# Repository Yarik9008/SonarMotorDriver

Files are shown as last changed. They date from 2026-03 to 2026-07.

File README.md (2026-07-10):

# SonarMotorDriver

Проект драйвера шагового двигателя с замкнутым контуром управления (PID) по абсолютному энкодеру LENZ IRS (BiSS C). В репозитории — прошивка для **STM32F103C8**, 3D-сборка платы, даташиты и иллюстрации.

> **Примечание:** Управление TMC2209 по UART (ток, микрошаг, вращение) проверено на аппаратуре целевой платы — мотор вращается, энкодер отвечает, драйвер подтверждает конфигурацию (`mcfg`). Пин **DIAG** (StallGuard/Open Load) разведён, но программно не опрашивается.

## Иллюстрации

| CAD: сборка с радиатором | CAD: сборка с прозрачным кожухом |
| --- | --- |
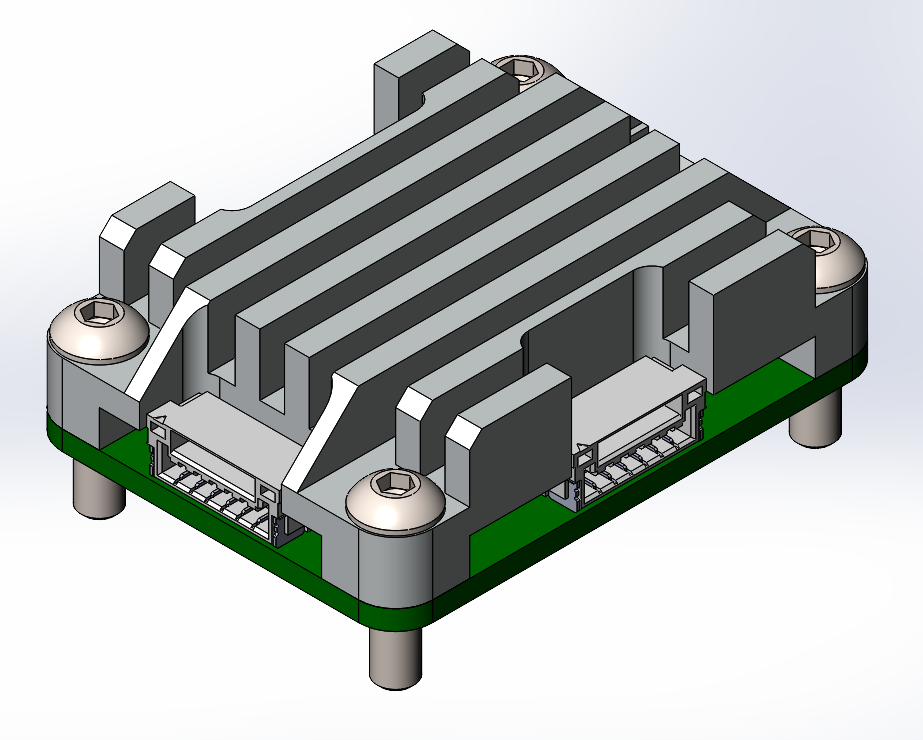
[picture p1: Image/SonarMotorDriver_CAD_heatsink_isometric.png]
CAD сборка с радиатором
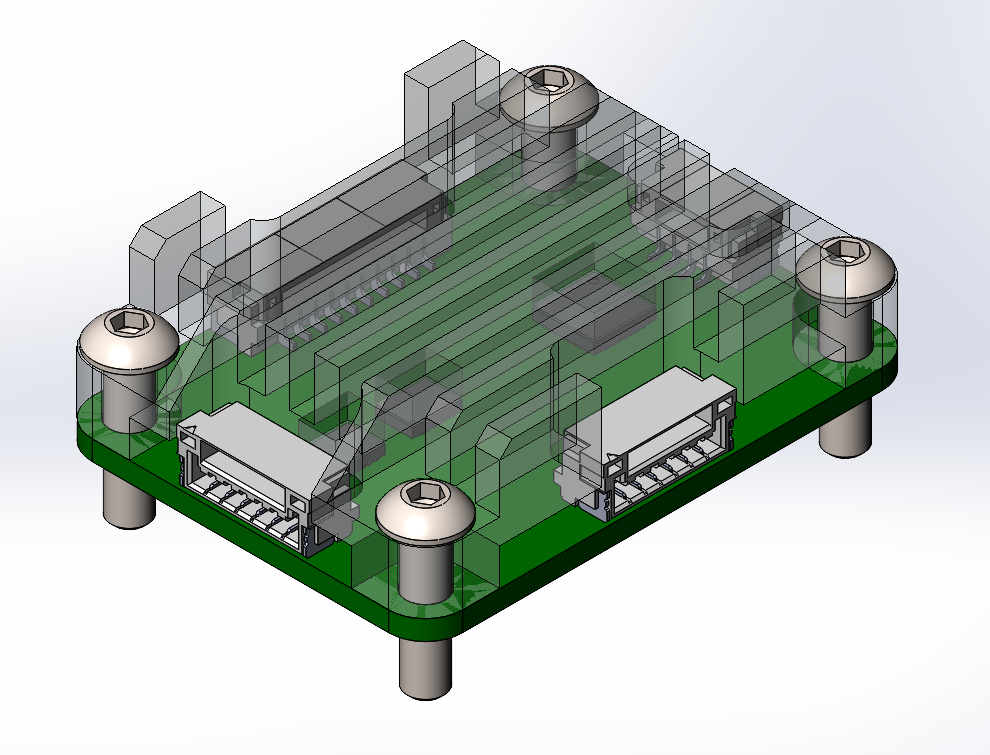
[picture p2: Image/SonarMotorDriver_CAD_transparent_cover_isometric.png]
CAD сборка с прозрачным кожухом
|  |  |

| Плата: верхний слой (релиз 0.1) | Плата: нижний слой (релиз 0.1) |
| --- | --- |
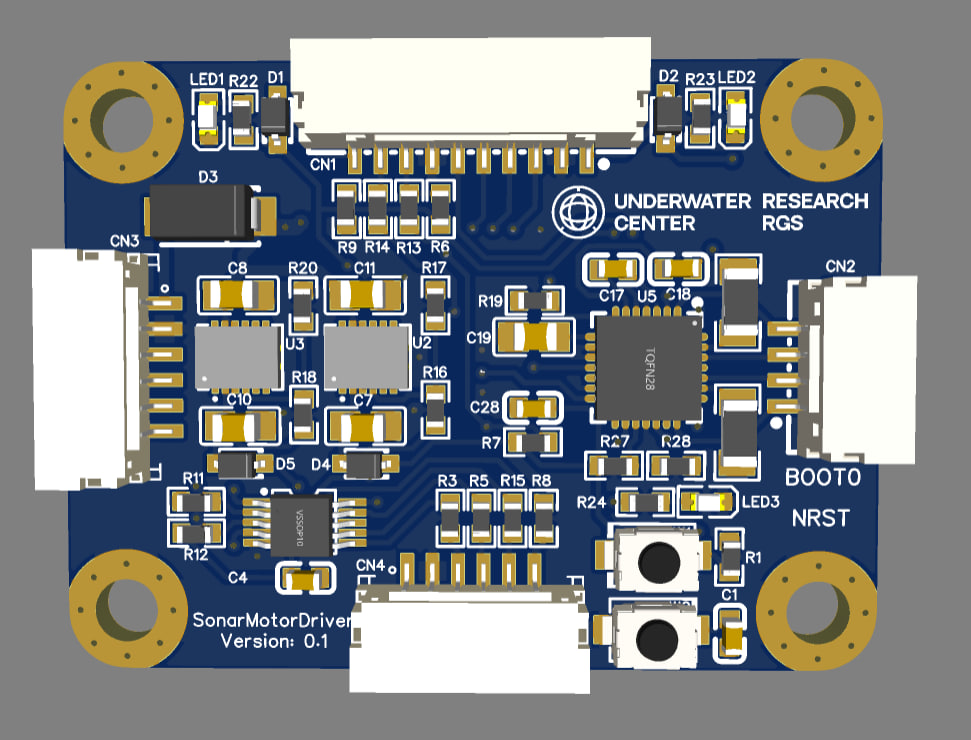
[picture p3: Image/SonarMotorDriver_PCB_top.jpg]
Верхний слой платы SonarMotorDriver
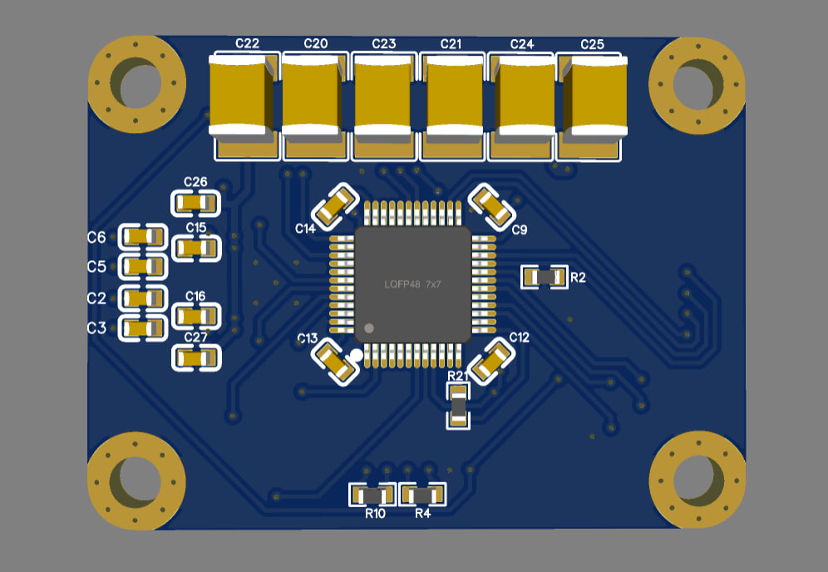
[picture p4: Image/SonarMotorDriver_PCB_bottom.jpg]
Нижний слой платы SonarMotorDriver
|  |  |

## Структура репозитория

| Каталог | Описание |
|---|---|
| [**Software/FW_SonarMotorDriver/**](Software/FW_SonarMotorDriver/) | Основная прошивка STM32F103C8: PID, энкодер BiSS C, TMC2209, **UART** (команды и телеметрия), IWDG |
| [**Software/FW_SonarMotorDriver_Sim/**](Software/FW_SonarMotorDriver_Sim/) | Имитатор основной прошивки: тот же UART-протокол (команды и телеметрия), но без реального энкодера и TMC2209 — для отладки ПО верхнего уровня без подключённого мотора |
| [**Software/Test_TMC2209/**](Software/Test_TMC2209/) | Отладочная прошивка **STM32F103C8** + TMC2209: **UART CLI** через внешний USB-UART переходник, проверка драйвера отдельно от основной платы |
| [**Hardware/CAD/**](Hardware/CAD/) | 3D-модели (SolidWorks/STEP): сборка с радиатором и кожухом, радиатор, STEP компонентов BOM |
| [**Docs/Datasheet/**](Docs/Datasheet/) | PDF-даташиты ключевых компонентов (STM32, TMC2209, THVD1452, питание, разъёмы и т.д.) |
| [**Image/**](Image/) | Рендеры платы и CAD для документации |

## Возможности (основная прошивка)

- **PID** — замкнутый контур по энкодеру, привязка к микрошагу, переход в open-loop при потере связи с энкодером
- **LENZ IRS** — абсолютная позиция 17–18 бит по BiSS C (SPI + DMA + THVD1452)
- **TMC2209** — STEP/DIR/ENABLE, UART для тока и микрошага
- **UART (USART1)** — текстовые команды и телеметрия (период настраивается, режимы `debug=0` / `debug=1`)
- **IWDG** — сторожевой таймер

Подробности, распиновка, протокол команд и BiSS C — в [Software/FW_SonarMotorDriver/README.md](Software/FW_SonarMotorDriver/README.md).

## Быстрый старт (сборка основной прошивки)

```bash
cd Software/FW_SonarMotorDriver
pio run                    # сборка
pio run --target upload    # прошивка (см. platformio.ini: ST-Link / WCH-Link + OpenOCD)
```

Имитатор UART-протокола (без мотора и энкодера): [Software/FW_SonarMotorDriver_Sim/README.md](Software/FW_SonarMotorDriver_Sim/README.md).
Тестовая прошивка драйвера TMC2209: [Software/Test_TMC2209/README.md](Software/Test_TMC2209/README.md).

## Требования

- **PlatformIO** — сборка прошивок в `Software/`
- **Программатор** — ST-Link, CMSIS-DAP или иной, совместимый с настройками `upload` в `platformio.ini`

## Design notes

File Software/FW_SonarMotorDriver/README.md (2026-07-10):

# FW_SonarMotorDriver — Closed-Loop Stepper

Прошивка для STM32F103C8 (Blue Pill): позиционное управление шаговым двигателем
через **TMC2209** с обратной связью от абсолютного энкодера **LENZ IRS** (BiSS C).
При потере энкодера — автоматический переход в **open-loop**. Настройка и мониторинг — через **UART** (PA9/PA10).

> **Примечание:** Управление TMC2209 по UART (ток, микрошаг, вращение STEP/DIR) проверено на аппаратуре — мотор вращается, энкодер отвечает (`ec:0`), `mcfg` подтверждает конфигурацию драйвера. Пин **DIAG** (StallGuard/Open Load) разведён, но программно не опрашивается.
>
> **См. также:** [FW_SonarMotorDriver_Sim](../FW_SonarMotorDriver_Sim/README.md) — имитатор этого же UART-протокола без реального энкодера и TMC2209, для отладки ПО верхнего уровня.

## Содержание

- [Архитектура](#архитектура)
- [Аппаратная часть](#аппаратная-часть)
- [Структура проекта](#структура-проекта)
- [Сборка и прошивка](#сборка-и-прошивка)
- [Использование](#использование)
- [Конфигурация](#конфигурация)
- [API модулей](#api-модулей)
- [Протокол BiSS C](#протокол-biss-c)
- [Устранение неисправностей](#устранение-неисправностей)

---

## Архитектура

```
                    Замкнутый контур управления (1 кГц)

 Уставка       ошибка   ┌─────────┐   шаги    ┌──────────────────────┐
 (t=X) ──────►(Σ)──────►│   PID   ├──────────►│ MotorDriver          ├──────► Мотор
               ▲ −      │ Kp+Ki+Kd│           │ (STEP_DIR или UART)  │    │
               │        └─────────┘           └──────────────────────┘    │
               │                                                          │
               │        ┌──────────────────┐                              │
               └────────┤  Encoder + BiSS  │◄─────────────────────────────┘
            pos_deg     │  SPI+DMA+THVD1452│   обратная связь
                        └──────────────────┘

 CL: PID(target − pos) → шаги (основной)
 OL: clamp(target − ol_pos) → шаги (при потере энкодера ≥ 500 мс)

 ┌──────┐   UART    ┌──────────┐
 │  ПК  │◄─────────►│   Cmd    ├──► en / dis / t= / t=± / kp= / ki= / kd= / op= / scan= / stop
 │      │  USART1   │  Parser  │
 └──────┘ PA9/PA10  └──────────┘
 ПК ◄── Телеметрия (UART TX): debug=0 → cp,ec; debug=1 → cp,tp,pe,u,m,ec,kp,ki,kd
```

### Режимы управления

| Режим | Условие | Поведение |
| --- | --- | --- |
| **cl** (closed-loop) | Энкодер отвечает | PID по ошибке `target − position`, вывод ограничен deadband |
| **ol** (open-loop) | Энкодер не отвечает ≥500 мс | Прямое позиционирование: `clamp(target − ol_pos)` без PID |

Переключение автоматическое:

- **cl → ol:** после `ENCODER_FAIL_MS` (500 мс) без ответа энкодера.
- **ol → cl:** при первом успешном ответе, интеграл PID сбрасывается.

### Стартовая диагностика энкодера

До включения мотора прошивка выполняет серию из `ENCODER_DIAG_SAMPLES` (16) чтений BiSS C
с интервалом `ENCODER_DIAG_INTERVAL_MS` (2 мс) и разрешает автоматический выход в «дом» только если:

- валидных ответов (OK/WARNING) не меньше `ENCODER_DIAG_MIN_OK` (12 из 16);
- разброс позиции при неподвижном вале не превышает `ENCODER_DIAG_MAX_SPREAD_DEG` (0.5°).

Результат отправляется хосту одной строкой:

```
enc:ok n=16/16 spread=0.004 pos=37.52     ← диагностика пройдена, далее хоуминг
err:enc n=3/16 spread=0.000 last=2        ← провал: мотор остаётся выключенным
```

При провале позиция продолжает отслеживаться, но движение возможно только по явной
команде оператора (`en`, `t=…`). Ту же проверку можно запустить в любой момент командой `diag`
(на остановленном моторе): ответ `ok:diag`, затем через ~16 мс строка `enc:ok` / `err:enc`.

### Фильтр выбросов показаний энкодера

CRC6 кадра BiSS слабая (искажённый кадр проходит проверку с вероятностью ~1/64), поэтому
поверх CRC работает фильтр правдоподобия: показание отбрасывается, если сдвиг от последней
принятой позиции превышает физически возможный — `ENCODER_OUTLIER_MAX_DELTA_DEG` (3°) за тик
1 мс (потолок скорости 1200°/с = 1.2°/мс, порог с запасом 2.5×). Бюджет сдвига масштабируется
на длительность пропуска данных (до 60° — дальше дельта неоднозначна из-за перехода через ноль).

- Отброшенное показание не попадает в контур управления (тик считается «без данных»),
  в телеметрии на этот момент `ec:6`, накопительный счётчик — поле `of` (debug=1).
- Реальный скачок позиции (проскальзывание муфты, восстановление энкодера после долгой
  потери связи на ходу) отличается от выброса устойчивостью: `ENCODER_OUTLIER_STREAK` (3)
  согласных чтений подряд — и новая позиция принимается (перепривязка за ~3 мс).

### Контур (1 кГц)

1. **TIM2** — флаг UIF каждые 1 мс.
2. **BiSS C** — чтение позиции через SPI1 + DMA + THVD1452 (неблокирующее).
3. **Encoder_Accumulate** — многооборотная позиция с обработкой перехлёста.
4. **Mode_Update** — счётчик сбоев: ≥500 мс без ответа → ol; при ответе → cl.
5. **MotorControl_Tick** — CL: PID → шаги; OL: прямое позиционирование.
6. **Stall_Tick** — защита от блокировки вала (см. ниже).
7. **Scan_Tick** — сканирование сектора (zigzag start↔end или бесконечное в одном направлении, до команды stop); пин синхронизатора PB9 (SYNC_OUT).
8. **Telemetry_Tick** — периодический вывод (250 Гц по умолчанию): debug=0 → cp,ec; debug=1 → полная.
9. **Heartbeat_Tick** — мигание LED ~1 Гц.

### Профиль движения: скорость и ускорение (v= / a=)

Пределы движения настраиваются на лету, без перепрошивки:

- **`v=<°/с>`** — рабочий предел скорости (1..1200). Действует на все виды движения:
  позиционирование, сканирование, непрерывное вращение. По умолчанию 1200 °/с.
- **`a=<°/с²>`** — предел ускорения (0..100000). По умолчанию **0 = без рампы**
  (скорость меняется мгновенно — поведение как раньше). При `a > 0`:
  - скорость нарастает/спадает не быстрее `a` (трапецеидальная рампа);
  - при подъезде к цели действует тормозной конверт `v ≤ sqrt(2·a·|ошибка|)` —
    мотор успевает остановиться без перелёта.

Текущие значения видны в полной телеметрии (`debug=1`, поля `v` и `a`).
Ограничение применяется поверх PID: выход регулятора обрезается по скорости
и ускорению перед квантованием в микрошаги.

### Защита от блокировки вала (stall)

В closed-loop прошивка сравнивает скомандованный путь с фактическим смещением вала
по энкодеру. Если за `STALL_TIMEOUT_MS` (1 с) мотору скомандовано не меньше
`STALL_MIN_CMD_DEG` (1°), а вал сместился меньше чем на `STALL_MEAS_FRACTION` (25%)
этого пути — вал считается заблокированным:

- драйвер выключается (ENN = HIGH, как по команде `dis`), сканирование и вращение сбрасываются;
- хост получает строку `err:stall cmd=<скомандовано°> meas=<фактически°> pos=<позиция°>`;
- возврат в работу — командой `en` (цель привязывается к текущей позиции, рывка не будет).

Защита действует при любом движении в CL: позиционирование `t=`, хоуминг, сканирование
`scan=`, непрерывное вращение `t=+`/`t=-`. В open-loop (энкодер недоступен) фактическое
положение вала неизвестно и защита не работает. Пороги — в `board.h` (`STALL_*`).

### Устойчивость приёма команд (UART RX)

RX работает через DMA в циклическом режиме. При ошибке линии (шум при подключении/отключении разъёма, framing error, overrun) HAL останавливает DMA-приём — без восстановления команды перестали бы приниматься до перезагрузки. `HAL_UART_ErrorCallback()` в `uart.c` сбрасывает флаги ошибок и перезапускает `HAL_UART_Receive_DMA()`, так что приём восстанавливается автоматически в течение одного тика. Передача телеметрии (TX) этой ошибкой не затрагивается и продолжается всегда.

### Приоритеты прерываний

| Приоритет | Источник | Назначение |
| --- | --- | --- |
| 4 | DMA1_Ch2/Ch3 | SPI1 RX/TX для BiSS C |
| 6 | USART1 | IDLE line detection (cmd UART) |
| 6 | DMA1_Ch4/Ch5 | UART TX/RX DMA (команды, тел.) |
| 15 | SysTick | HAL_GetTick() (для таймаутов HAL) |

---

## Аппаратная часть

> [!IMPORTANT]
> **Питание драйвера (VS):** Драйвер TMC2209 необходимо всегда подключать с дополнительным электролитическим конденсатором (рекомендуется 100–470 мкФ) по линии питания **VS** (как можно ближе к пинам VS и GND) для сглаживания бросков напряжения и защиты чипа.

### Выводы STM32

| Вывод | Функция | Назначение |
| ----- | --- | --- |
| PA5 | SPI1_SCK | MA → THVD1452 D |
| PA6 | SPI1_MISO | SLO ← THVD1452 R |
| PA9 | USART1_TX | UART TX (команды, телеметрия) → ПК |
| PA10  | USART1_RX | UART RX (команды) ← ПК |
| PB0 | GPIO_OUT (DE) | Driver Enable THVD1452 (active HIGH) |
| PB1 | GPIO_OUT (RE) | Receiver Enable THVD1452 (active LOW) |
| PA2 | USART2_TX | UART TMC2209 → PDN_UART (через 1 кОм) |
| PA3 | USART2_RX | UART TMC2209 ← PDN_UART (общая линия) |
| PB6 | GPIO_OUT | ENN TMC2209 (LOW = вкл) |
| PB7 | GPIO_OUT | DIR TMC2209 |
| PB8 | TIM4_CH3 AF | STEP TMC2209 (PWM) |
| PA7 | GPIO_IN | DIAG TMC2209 (StallGuard, Open Load; HIGH = ошибка) |
| PB9 | GPIO_OUT | SYNC_OUT (HIGH=позиция достигнута, LOW=движение) |
| PB12  | GPIO_IN | SYNC_IN (внешний триггер синхронизации) |
| PC13  | GPIO_OUT | LED heartbeat (~1 Гц) |

### Схема подключения

```
  STM32F103          THVD1452                  Энкодер LENZ IRS
 ┌──────────┐      ┌──────────┐      ┌──────────────────────────┐
 │      PA5 ├─────►│ D      Y ├─────►│ MA+  (pin 3, жёлтый)     │
 │ (SPI_SCK)│      │        Z ├─────►│ MA−  (pin 4, зелёный)    │
 │      PA6 │◄─────┤ R      A │◄─────┤ SLO+ (pin 5, синий)      │
 │(SPI_MISO)│      │        B │◄─────┤ SLO− (pin 6, белый)      │
 │      PB0 ├─────►│ DE       │      │                          │
 │      PB1 ├─────►│ RE       │      │                          │
 └──┬───┬───┘      └──────────┘      └──────────────────────────┘
    │   │
    │   │            TMC2209                      Шаговый двигатель
    │   │         ┌──────────────┐      ┌──────────────────────────┐
    │   ├── PB8 ─►│ STEP      A1 ├─────►│ зелёный  (обмотка A)     │
    │   ├── PB7 ─►│ DIR       A2 ├─────►│ чёрный   (обмотка A)     │
    │   ├── PB6 ─►│ ENN       B1 ├─────►│ синий    (обмотка B)     │
    │   ├── PA2 ─►│ PDN_UART  B2 ├─────►│ красный  (обмотка B)     │
    │   ├── PA3 ◄─┤ PDN_UART     │      │                          │
    │   └── PA7 ◄─┤ DIAG         │      │                          │
    │             └──────────────┘      └──────────────────────────┘
    ├── PB9  ──►  SYNC_OUT (позиция достигнута)
    ├── PA9  ──►  UART TX ──► ПК (115200 8N1)
    ├── PA10 ◄──  UART RX ◄── ПК
    ├── PB12 ◄──  SYNC_IN (внешний триггер)
    └── PA9/PA10 ── UART → ПК (COM-порт, команды и телеметрия)
```

### Распиновка TMC2209

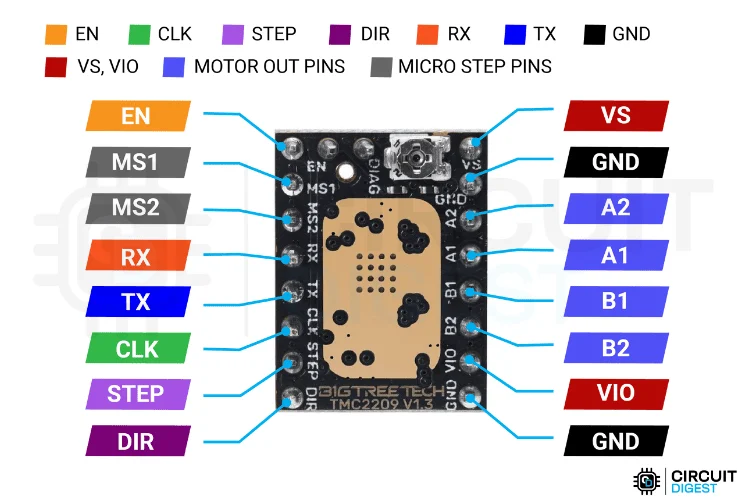
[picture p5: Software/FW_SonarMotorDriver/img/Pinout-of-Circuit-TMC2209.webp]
Распиновка TMC2209


| Контакт | Описание |
| --- | --- |
| **EN** | Enable — разрешение работы драйвера. LOW = включён, HIGH = отключён (обмотки обесточены) |
| **MS1** | Microstep select 1 — вместе с MS2 задаёт режим микрошага (таблица в датащите) |
| **MS2** | Microstep select 2 — вместе с MS1 задаёт режим микрошага |
| **RX** | UART RX (PDN_UART) — приём данных от MCU для конфигурации по UART |
| **TX** | UART TX (PDN_UART) — передача данных в MCU (общая линия с RX через резистор) |
| **CLK** | Clock — внешний тактовый сигнал (оставить незаземлённым для использования внутреннего RC) |
| **STEP** | Step — вход импульсов шага от MCU. Каждый импульс HIGH→LOW = один микрошаг |
| **DIR** | Direction — направление вращения. HIGH = вперёд, LOW = назад |
| **VS** | Motor supply voltage — питание силовой части (обмоток), 4.75–29 В. **Обязателен внешний конденсатор!** |
| **GND** | Ground — общий минус |
| **A1** | Обмотка A, вывод 1 — первый провод первой обмотки шагового двигателя |
| **A2** | Обмотка A, вывод 2 — второй провод первой обмотки шагового двигателя |
| **B1** | Обмотка B, вывод 1 — первый провод второй обмотки шагового двигателя |
| **B2** | Обмотка B, вывод 2 — второй провод второй обмотки шагового двигателя |
| **VIO** | Logic supply voltage — питание логической части (3.3–5 В) |

### Выводы энкодера

| Пин | Функция | Цвет провода |
| --- | --- | --- |
| 1 | Vcc | Красный |
| 2 | GND | Чёрный |
| 3 | MA+ | Жёлтый |
| 4 | MA− | Зелёный |
| 5 | SLO+ | Синий |
| 6 | SLO− | Белый |

Разъём: Amphenol FCI 10114830-11106LF.

### Подключение шагового двигателя (4 провода)

Двигатель с проводами **синий**, **зелёный**, **красный** и **чёрный** подключается к выходам TMC2209 (обмотки A и B) следующим образом:

| Подключение TMC2209 | Цвет провода |
| --- | --- |
| A1 | Зелёный |
| A2 | Чёрный |
| B1 | Синий |
| B2 | Красный |

Зелёный и чёрный — одна обмотка (A), синий и красный — вторая обмотка (B). Если направление вращения противоположное ожидаемому, поменяйте местами провода одной обмотки (например, A1↔A2 или B1↔B2).

### Тактирование

Источник: HSI

| Домен | Частота |
| --- | --- |
| SYSCLK | 48 МГц |
| APB1 | 24 МГц |
| APB2 | 48 МГц |
| SPI1 (MA)  | 0.75 МГц (APB2/64) |
| TIM2 | 48 МГц (APB1 × 2)  |
| DWT CYCCNT | 48 МГц (SYSCLK) |
| TIM4 | 48 МГц (APB1 × 2)  |

Проект использует **единый моторный фасад** внутри библиотеки `lib/tmc2209`, который объединяет:

- **Core Driver** — низкоуровневая библиотека для TMC2209 (регистры, UART, конфиг).
- **Platform Port** — STM32 HAL-специфичная реализация (GPIO, TIM, UART к TMC2209 на `USART2`).
- **Motor Backend** — логика генерации импульсов (STEP/DIR через TIM4 или UART VACTUAL).
- **Diagnostics** — периодический опрос `DRV_STATUS` каждые 500 мс **только на остановленном моторе**: обмен по UART блокирующий (~4–5 мс), на ходу он прерывал бы поток STEP-импульсов (периодический рывок), поэтому во время движения/сканирования пропускается.

Приложение работает только с высокоуровневым API: `tmc2209_motor_init()`, `tmc2209_motor_set_enabled()`, `tmc2209_motor_move_steps()`, `tmc2209_motor_stop()` и т.д. Команды конфигурации во время выполнения (`irun`, `ihold`, `mstep`) возвращают дифференцированные коды ошибок:

- `ok` — успешно применено.
- `err:not ready` — драйвер не инициализирован.
- `err:bad arg` — недопустимый аргумент (например, неверный ток или шаг).
- `err:apply failed` — ошибка связи или применения настройки в чип.

### Режимы управления двигателем (board.h: MOTOR_DRIVER_MODE)

| Режим | Значение | Описание |
| --- | --- | --- |
| STEP_DIR | 0 | STEP/DIR импульсы от MCU (TIM4). Основной режим, позиционное управление. |
| UART | 1 | VACTUAL / internal pulse generator TMC2209. Движение через UART API. |

Режим задаётся compile-time в `board.h`:

```c
#define MOTOR_DRIVER_MODE  MOTOR_DRIVER_MODE_STEP_DIR_VAL  /* или MOTOR_DRIVER_MODE_UART_VAL */
```

### Инициализация

Один шаг `tmc2209_motor_init()` заменяет старые подходы. Внутри:

1. Инициализация UART к TMC2209 (USART2, blocking)
2. Инициализация lib/tmc2209 (конфиг, проверка связи)
3. STEP/DIR backend (если режим STEP_DIR): GPIO STEP/DIR, TIM4 PWM с preload
4. Подготовка subsystem без скрытого изменения enable state; политика включения выполняется приложением отдельным вызовом `tmc2209_motor_set_enabled()`

### Удалённые элементы

- Отдельный `stepper.c` — функциональность перенесена внутрь фасада
- Устаревшие `TMC2209_InitStart()` / `TMC2209_Poll()` — заменены на единый `tmc2209_motor_init()`
- Двойное управление ENN — теперь только через `tmc2209_motor_set_enabled()`

---

## Структура проекта

```
FW_SonarMotorDriver/
├── platformio.ini
├── include/
│   ├── board.h              — выводы, MOTOR_DRIVER_MODE, TMC2209_MICROSTEPS, PID
│   ├── stm32f1xx_hal_conf.h — конфигурация HAL
│   ├── biss_c.h             — BiSS C интерфейс
│   ├── pid.h                — PID-регулятор
│   ├── uart.h               — UART (USART1) API
│   └── cmd_parser.h         — парсер команд en/dis/t/t±/kp/ki/kd/op/debug/scan/stop
├── src/
│   ├── main.c               — init, главный цикл, контроллер, телеметрия
│   ├── biss_c.c             — BiSS C: SPI + DMA, CRC6, разбор кадра
│   ├── pid.c                — PID с anti-windup
│   ├── cmd_parser.c         — парсер команд (UART)
│   └── uart.c               — UART (USART1 PA9/PA10): RX DMA circular + IDLE, TX DMA
├── lib/
│   └── tmc2209/             — библиотека драйвера TMC2209 (core API + STM32 port + motor facade)
└── tools/
    ├── read_serial.py       — утилита чтения COM-порта
    └── test_commands.py     — автотест всех команд с логом (привязка по времени)
```

| Модуль | Содержание |
| --- | --- |
| `board.h` | Константы: выводы, MOTOR_DRIVER_MODE, TMC2209_MICROSTEPS (256), PID, буферы |
| `main.c` | BSP, clock, TIM2, DWT, init, CL/OL контроллер, команды, телеметрия. Вызывает tmc2209_motor_* |
| `lib/tmc2209` | Изолированная библиотека: регистры, UART к TMC2209 на `USART2`, порт STM32, генерация STEP/DIR (TIM4), диагностика |
| `uart.c` | Драйвер command UART на `USART1`: RX через DMA Circular + IDLE line, TX через DMA. Кольцевые буферы. При ошибке линии (шум/framing/overrun) автоматически перезапускает RX DMA (`HAL_UART_ErrorCallback`), чтобы приём команд не зависал навсегда. |
| `biss_c` | BiSS C: SPI + DMA, разбор кадра, CRC6 |
| `pid` | PID с anti-windup и ограничением выхода |
| `cmd_parser`  | Парсер команд (en, dis, t=, t=±, kp=, ki=, kd=, op=, debug=, scan=, stop) |
| `uart` | UART (USART1 PA9/PA10): **DMA circular RX + IDLE**, **DMA TX**. Обслуживает только командный интерфейс и телеметрию ПК. |

---

## Сборка и прошивка

**Требования:** [PlatformIO CLI](https://docs.platformio.org/en/latest/core/installation.html) (или расширение для VS Code / Cursor), программатор ST-Link или совместимый (в `platformio.ini` по умолчанию задан WCH-Link через OpenOCD).

```bash
pio run                   # Сборка
pio run --target upload   # Прошивка
```

**IDE (IntelliSense):** при ошибке `'stm32f1xx_hal.h' file not found` — это IntelliSense, сборка проходит. Решение: `pio run -t compiledb` для генерации `compile_commands.json`, затем перезагрузка окна (Ctrl+Shift+P → "Developer: Reload Window"). Убедитесь, что выбран конфиг **PlatformIO** в статус-баре C/C++.

---

## Использование

### Подключение

1. Энкодер LENZ IRS → THVD1452 → PA5/PA6, PB0/PB1.
2. TMC2209: STEP→PB8, DIR→PB7, ENN→PB6, PDN_UART↔PA2/PA3 (UART TX/RX), DIAG→PA7.
3. Питание энкодера 5–12 В, питание драйвера.
4. UART команд и телеметрии: PA9 (TX) / PA10 (RX) → ПК (разъём J2: Pin 4 TX, Pin 3 RX), открыть COM-порт.
5. **UART bootloader** (прошивка): BOOT0=1 при сбросе; для загрузки использовать PA9/PA10 (те же контакты).

### Команды (UART)

| Команда | Действие | Ответ |
| --- | --- | --- |
| `en` | Включить драйвер + PID (при старте контроллер по умолчанию включен)  | `ok:en` |
| `dis` | Выключить драйвер | `ok:dis` |
| `t=180` | Целевая позиция (градусы) | `ok:t=180.00` |
| `t=+` | Бесконечное вращение в положительном направлении | `ok:t=+` |
| `t=-` | Бесконечное вращение в отрицательном направлении | `ok:t=-` |
| `kp=0.025` | Установить Kp (рекомендуемый 0.025) | `ok:kp=0.0250` |
| `ki=0` | Установить Ki | `ok:ki=0.0000` |
| `kd=0` | Установить Kd | `ok:kd=0.0000` |
| `v=600` | Предел скорости движения, °/с (1..1200) | `ok:v=600.0` / `err:bad arg` |
| `a=2000` | Предел ускорения, °/с² (0..100000; 0 = без рампы) | `ok:a=2000.0` / `err:bad arg` |
| `op=50` | Период телеметрии (мс), 0=выкл | `ok:op=50` |
| `debug=0` | Минимальная телеметрия (cp,ec) | `ok:debug=0` |
| `debug=1` | Полная телеметрия | `ok:debug=1` |
| `scan=s,e,st,d` | Сканирование сектора (start°, end°, step°, delay_ms); zigzag до stop. Пример: 0..180°, шаг 10°, задержка 100 мс: `scan=0,180,10,100` | `ok:scan=s,e,st,d` / `err:scan` |
| `scan=s,+,st,d` | Бесконечное сканирование вперёд (start°, step°, delay_ms) | `ok:scan=s,+,st,d` |
| `scan=s,-,st,d` | Бесконечное сканирование назад (start°, step°, delay_ms) | `ok:scan=s,-,st,d` |
| `stop` | Остановить мотор (любое движение, в т.ч. сканирование и вращение) | `ok:stop` |
| `irun 600` | Установить рабочий ток (мА) | `ok:irun=600` / `err:...` |
| `ihold 300` | Установить ток удержания (мА) | `ok:ihold=300` / `err:...` |
| `icur 600 300`  | Установить оба тока: рабочий и удержания (мА) | `ok:icur=600,300` / `err:...` |
| `mstep 256` | Установить микрошаг (рекомендуемый 256; 1/2/4/8/16/32/64/128/256) | `ok:mstep=256` / `err:...` |
| `mcfg` | Вывести конфигурацию драйвера (mode, run, hold, microsteps, ready) | `mode=... run=... hold=...` |
| `diag` | Диагностика энкодера (16 чтений на остановленном моторе) | `ok:diag`, затем `enc:ok ...` / `err:enc ...` (или `err:busy...`) |

**Автотест команд:** `python tools/test_commands.py COM19` — проверяет все команды и пишет лог в `logs/fw_test_YYYYMMDD_HHMMSS.log` с привязкой по времени. Каталог `logs/` создаётся при первом запуске. Использует рекомендуемые параметры из прошивки (Kp 0.025, Ki/Kd 0, IRUN 600, IHOLD 300, микрошаг 256, op=4); для PID сначала Kp в два раза меньше (0.0125), затем 0.025; для сканирования — полный тест зигзага 0..180°, **шаг 10°**, задержка **100 мс**: после команды `scan=0,180,10,100` скрипт ждёт **~30 с** (полный проход), затем отправляет `stop`. Ответы CLI формируются как цельные строки с `\r\n`, а телеметрия по возможности не вклинивается перед уже стоящим в очереди ответом. Быстрый прогон: `--no-full-scan` (ожидание 5 с).

### Непрерывное вращение

Режим бесконечного вращения мотора или движения с заданной скоростью без PID-регулирования. 
В режиме **STEP_DIR**: мотор шагает на `steps` шагов КАЖДЫЙ тик (1 мс) в заданном направлении. 
В режиме **UART**: устанавливается соответствующий `VACTUAL`.

**Команды:**

| Команда | Направление |
| --- | --- |
| `t=+` | Положительное (CW)  |
| `t=-` | Отрицательное (CCW) |

**Остановка:** любая из команд `stop`, `dis`, `t=X` (конкретная позиция), `en`, `scan=...`.

**Защита от переполнения:** счётчики позиции (`g_ol_pos_deg`, `g_target_deg`, `g_enc_counts`) периодически сбрасываются к нулю при достижении ±10 млн градусов (~28 тыс. оборотов), чтобы float не терял точность.

**Примеры:**

```
t=+     # Бесконечное вращение вперёд
t=-     # Бесконечное вращение назад
stop    # Остановить
t=90    # Остановить вращение и перейти к позиции 90°
```

### Сканирование сектора

Режим автоматического перемещения по заданному угловому сектору с фиксированным шагом и задержкой на каждой позиции. Предназначен для синхронизации с внешним оборудованием (сонар, камера, датчик) через пин синхронизатора.

#### Зигзаг-сканирование

**Команда:** `scan=start,end,step,delay`

| Параметр | Единица | Описание |
| --- | --- | --- |
| start | ° | Начальный угол сектора |
| end | ° | Конечный угол сектора (обязательно > start) |
| step | ° | Шаг (должен быть > 0) |
| delay | мс | Задержка на каждой позиции после достижения цели (> 0, иначе `err:scan`) |

**Траектория (zigzag):** мотор движется туда-обратно по сектору в бесконечном цикле до команды `stop`:

```
start → start+step → … → end → end−step → … → start → …
```

1-й проход: в сторону увеличения угла (start → end).  
2-й проход: в сторону уменьшения (end → start).  
Далее цикл повторяется.

#### Бесконечное сканирование

**Команда:** `scan=start,+,step,delay` или `scan=start,-,step,delay`

| Параметр  | Единица | Описание |
| --- | --- | --- |
| start | ° | Начальная позиция |
| `+` / `-` | — | Направление: `+` = вперёд, `-` = назад |
| step | ° | Шаг (должен быть > 0) |
| delay | мс | Задержка на каждой позиции (> 0) |

Мотор шагает на `step` градусов, ждёт `delay` мс (с SYNC-импульсом), затем шагает снова — бесконечно в одном направлении до команды `stop`.

**Защита от переполнения:** при приближении позиции к ±10 млн градусов все счётчики синхронно сдвигаются к нулю.

#### Общее для режимов сканирования

**Расчёт задержки в режиме сканирования**

Параметр `delay` задаёт время ожидания (в миллисекундах) на каждой позиции после того, как мотор достиг цели (ошибка PID в пределах deadband). Задержка реализована счётчиком `g_scan_delay_cnt`, который инкрементируется в `Scan_Tick()` при каждом вызове из обработчика **TIM2** (частота 1 кГц, период 1 мс):

```
g_scan_delay_cnt++
if (g_scan_delay_cnt < g_scan_delay_ms) return;  // ждём дальше
```

Таким образом, `delay=10` означает 10 мс, `delay=50` — 50 мс. Точность привязки к SysTick: ±1 мс.

**SYNC_OUT (PB9)** — выход для синхронизации с внешним оборудованием:

| Уровень  | Момент |
| --- | --- |
| **LOW**  | Начало перемещения к следующей позиции |
| **HIGH** | Целевая позиция достигнута (мотор в deadband, ошибка менее 0.05°) |

Типичное применение: подключить PB9 к триггеру сонара/камеры — HIGH означает «позиция достигнута, можно делать замер». **SYNC_IN (PB12)** — вход для внешнего триггера синхронизации.

**Примеры:**

```
scan=0,90,5,10      # Зигзаг: сектор 0°–90°, шаг 5°, задержка 10 мс
scan=-45,45,2,50    # Зигзаг: сектор ±45°, шаг 2°, задержка 50 мс
scan=0,+,1.5,200    # Бесконечно вперёд: от 0°, шаг 1.5°, задержка 200 мс
scan=90,-,0.5,100   # Бесконечно назад: от 90°, шаг 0.5°, задержка 100 мс
stop                # Остановить сканирование (и любое движение)
```

**Ограничения:** мотор по умолчанию включается политикой приложения после успешной инициализации драйвера и первого чтения энкодера, поэтому сканирование обычно можно запускать сразу. После команды `dis` потребуется `en`. При неверных параметрах — ответ `err:scan`: для зигзага нужны **start < end**, **step > 0**, **delay > 0**; для бесконечного режима — **step > 0**, **delay > 0**.

### Телеметрия

Периодический вывод (по умолчанию 250 Гц, период 4 мс). Режим задаётся флагом `debug` (команда `debug=0` или `debug=1`):

- **debug=0** (по умолчанию) — минимальный: только позиция и код ошибки
- **debug=1** — полная телеметрия. При полной телеметрии фактический период вывода не меньше 20 мс (50 Гц), чтобы длинные строки успевали передаваться по UART
- При занятом TX ответы на команды имеют приоритет: телеметрия пропускает тик, пока очередь `USART1` не опустеет, что уменьшает рваные строки в логах

**Минимальный режим (debug=0):**

```
cp:179.82,ec:0
```

**Полный режим (debug=1):**

```
cp:179.82,tp:180.00,pe:0.18,u:0.0563,m:cl,ec:0,kp:0.0250,ki:0.0000,kd:0.0000,drp:0
cp:90.12,tp:180.00,pe:89.88,u:0.0000,m:ol,ec:2,kp:0.0250,ki:0.0000,kd:0.0000,drp:0
```

**Состав и типы (board.h):**

| Режим | Поля | Типы |
| --- | --- | --- |
| debug=0 | cp, ec | cp(float), ec(uint8_t) |
| debug=1 | cp, tp, pe, u, m, ec, kp, ki, kd, v, a, of, drp | cp,tp,pe,u(float), m(cl/ol), ec(uint8_t), kp,ki,kd,v,a(float), of,drp(uint32) |

| Поле | Описание |
| ---- | --- |
| `cp` | Current Position — текущая позиция энкодера, градусы |
| `tp` | Target Position — целевая позиция, градусы |
| `pe` | Position Error — ошибка позиционирования (tp − cp), градусы |
| `u`  | Control Output — управляющее воздействие, град/тик |
| `m`  | Mode — режим: `cl` closed-loop, `ol` open-loop |
| `ec` | Error Code — код ошибки энкодера (0 = OK, 1–5 см. таблицу)  |
| `kp`  | Коэффициент Kp PID |
| `ki`  | Коэффициент Ki PID |
| `kd`  | Коэффициент Kd PID |
| `v` | Предел скорости, °/с (команда `v=`) |
| `a` | Предел ускорения, °/с² (команда `a=`, 0 = выкл) |
| `of`  | Счётчик отфильтрованных выбросов энкодера |
| `drp` | Счётчик потерянных TX-пакетов (переполнение очереди UART)  |

**Коды ec:**

| ec  | Код | Описание |
| --- | --- | --- |
| 0 | OK | Нет ошибок. Энкодер отвечает корректно. |
| 1 | BiSS CRC | CRC6 в кадре BiSS не совпала. Данные повреждены при передаче. Причины: помехи в кабеле MA/SLO, длинный кабель без терминации, плохой контакт. |
| 2 | BiSS NO_RESP | Энкодер не ответил на опрос. Проверить: питание энкодера (5–12 В), трансивер THVD1452, распайку PA5/PA6/PB0/PB1, целостность кабеля. |
| 3 | BiSS SENSOR  | Бит Error в кадре BiSS = 0. Энкодер сообщает о невалидности данных (внутренняя ошибка датчика, инициализация, сбой питания). |
| 4 | BiSS WARN | Бит Warning в кадре BiSS = 0. Предупреждение о качестве данных. В текущей логике такие данные считаются пригодными (enc_ok = true). |
| 5 | BiSS SPI | Ошибка обмена SPI (HAL_SPI_TransmitReceive != HAL_OK). SPI не инициализирован, MISO не подключён, конфликт пинов. |
| 6 | ENC OUTLIER  | Показание отброшено фильтром выбросов: сдвиг позиции физически невозможен (см. «Фильтр выбросов»). Частые `ec:6` (растущий `of`) — помехи в линии энкодера. |

### Рекомендуемые (начальные) значения

Параметры заданы в `board.h` и используются при старте. Автотест `tools/test_commands.py` выставляет те же значения.

| Параметр | Рекомендуемое значение |
| --- | --- |
| **Kp, Ki, Kd** | 0.025, 0.0, 0.0 (PID_KP_DEFAULT, PID_KI_DEFAULT, PID_KD_DEFAULT) |
| **Deadband** | 0.05° (PID_DEADBAND_DEG) |
| **IRUN** | 600 мА (TMC2209_IRUN_MA) |
| **IHOLD** | 300 мА (TMC2209_IHOLD_MA) |
| **Микрошаг** | 256 (TMC2209_MICROSTEPS) |
| **Телеметрия** | период 4 мс (250 Гц); debug=0 (cp, ec) или debug=1 (полная) |
| **Драйвер** | subsystem инициализируется отдельно; включение делается приложением после первого ответа энкодера |
| **Макс. скор.**| 1200°/с (MAX_SPEED_DEG_S) |

---

## Конфигурация

Рекомендуемые параметры в `include/board.h` (совпадают с автотестом):

```c
#define POLL_INTERVAL_MS        1U       // 1 мс (1 кГц)
#define ENCODER_RESOLUTION_BITS 17U      // 17 или 18
#define ENCODER_COUNTS_REV      131072U  // 2^17
#define ENCODER_FAIL_MS         500U     // 500 мс без ответа → open-loop
#define MOTOR_FULL_STEPS_REV    200U     // 200 = 1.8°, 400 = 0.9°
#define TMC2209_MICROSTEPS      256U    // Рекомендуемый микрошаг: 1, 2, 4, 8, 16, 32, 64, 128, 256
#define TMC2209_IRUN_MA         600U     // Ток при движении, мА (рекомендуемый)
#define TMC2209_IHOLD_MA        300U     // Ток удержания, мА (рекомендуемый)
#define MAX_SPEED_DEG_S         1200U    // Максимальная скорость, град/с
#define PID_KP_DEFAULT          0.025f   // Kp по умолчанию (рекомендуемый)
#define PID_KI_DEFAULT          0.0f     // Ki по умолчанию
#define PID_KD_DEFAULT          0.0f     // Kd по умолчанию
#define PID_DEADBAND_DEG        0.05f    // Мёртвая зона PID, градусы (>= ENCODER_ACCURACY_DEG)
#define OUTPUT_PERIOD_MS_DEFAULT 4U      // Период телеметрии (мс), 0 = выкл; 4 мс = 250 Гц
#define OUTPUT_PERIOD_MS_DEBUG_MIN 20U   // При debug=1 период не меньше (мс), чтобы полные сообщения успевали по UART
#define TELEMETRY_DEBUG_DEFAULT 0        // 0 = cp,ec; 1 = полная телеметрия
#define STARTUP_TARGET_OFFSET_DEG 0.0f   // Офсет от 0° при старте; 0 = домашняя позиция
#define MOTOR_DRIVER_MODE       MOTOR_DRIVER_MODE_STEP_DIR_VAL  // или MOTOR_DRIVER_MODE_UART_VAL
#define SYNC_OUT_PORT           GPIOB   // SYNC_OUT (PB9)
#define SYNC_OUT_PIN            GPIO_PIN_9
#define SYNC_IN_PORT            GPIOB   // SYNC_IN (PB12)
#define SYNC_IN_PIN             GPIO_PIN_12
```

При старте: `tmc2209_motor_init()` только поднимает subsystem. Далее приложение **включает драйвер отдельно** после первого ответа энкодера, и мотор движется в домашнюю позицию (0° + офсет) кратчайшим путём. Команда `en` нужна только после `dis`.
Микрошаг и ток TMC2209 задаются по UART при старте (board.h: TMC2209_IRUN_MA, TMC2209_IHOLD_MA, TMC2209_MICROSTEPS).

### Частота опроса

| POLL_INTERVAL_MS | Частота |
| --- | --- |
| 1 | 1 кГц |
| 2 | 500 Гц  |
| 10 | 100 Гц  |
| 100 | 10 Гц |

### Разрешение энкодера

- **17** — IRS-I34, IRS-I50, IRS-I60
- **18** — IRS-I70, IRS-I80, IRS-I90

---

## API модулей

### BiSS C

```c
BiSS_Config cfg = { .spi_instance = SPI1, .resolution_bits = 17, ... };
BiSS_Init(&cfg);

BiSS_Reading rd;
BiSS_Status st = BiSS_Read(&rd);           // Блокирующее (инициализация)

BiSS_StartRead();                           // Неблокирующее (DMA)
if (BiSS_IsReady()) st = BiSS_GetResult(&rd);  // rd.position, rd.angle_deg
```

### TMC2209 Facade (единый API управления двигателем)

```c
tmc2209_motor_init();
tmc2209_motor_set_enabled(1);   // Включить (ENN = LOW)
tmc2209_motor_move_steps(10);   // Установка скорости 10 шагов/тик (для control loop)
tmc2209_motor_move_steps(-5);   // Установка скорости -5 шагов/тик
tmc2209_motor_stop();          // Остановить
tmc2209_motor_set_current(800, 400);   // run_ma, hold_ma
tmc2209_motor_set_microsteps(32);
tmc2209_motor_get_drv_status(&st);
tmc2209_motor_get_version(&ver);
```

### PID

```c
float deg = PID_Update(&pid, error, dt);
PID_Reset(&pid);
```

### UART

```c
UART_Init();
UART_Transmit((uint8_t *)"hello\r\n", 7);
UART_Task();                               // Вызывать в main loop
uint16_t len = UART_ReadLine(buf, 64);     // Чтение строки из RX буфера
```

---

## Протокол BiSS C

Синхронный протокол: ведущий генерирует MA, ведомый отвечает на SLO.

### Структура кадра

```
│◄─ ACK (4 такта) ──►│ Start │ CDS │◄────────── SCD (32 бита)───────────►│
│  1  1  1  1        │   0   │  1  │       P23…P0 │ E │ W │ CRC6         │
```

| Поле | Размер  | Описание |
| --- | --- | --- |
| Position | 24 бита | Абсолютная позиция (MSB) |
| Error | 1 бит | 1 = OK, 0 = ошибка |
| Warning  | 1 бит | 1 = OK, 0 = зазор |
| CRC6 | 6 бит | x^6+x^1+x^0 |

### Параметры

| Параметр | Значение |
| --- | --- |
| Частота MA | 0.1 – 5 МГц |
| Физический уровень | RS422, 5 В |
| Время готовности | 50 мс после включения |

---

## Устранение неисправностей

| Симптом | Причина | Решение |
| --- | --- | --- |
| `ec:2` (NO_RESP) | Энкодер не отвечает | Проверить THVD1452, питание энкодера |
| `ec:1` (CRC) | Помехи в кабеле | Терминация, укоротить кабель |
| `ec:3` (SENSOR) | Бит Error = 0 | Проверить питание, перезапустить |
| Мотор не двигается | Драйвер выключен | Команда `en` |
| Мотор дрожит на месте  | Deadband < шума энкодера | Увеличить PID_DEADBAND_DEG |
| LED не мигает | Зависание | Отладчик |
| Пропуски в терминале | UART не успевает | Увеличить `op` |
| Периодические рывки при движении (раз в ~0.5 с) | Блокирующий опрос DRV_STATUS TMC2209 рвал контур (исправлено: опрос только в простое) | Обновить прошивку |
| `err:unknown` в ответ  | Нераспознанная команда | Проверить формат (en/dis/t=/kp=/scan=/stop) |
| `err:enc ...` при старте | Энкодер не прошёл стартовую диагностику (нет ответа / позиция «плывёт») | Проверить питание/кабель энкодера, повторить `diag`; движение — вручную после `en` |
| `err:stall ...`, мотор обесточен | Вал заблокирован ≥1 с (механическое препятствие, клин, слишком низкий IRUN) | Устранить препятствие, проверить ток (`irun`), снова включить командой `en` |
| Плата не отвечает на команды (телеметрия при этом идёт) | Ошибка линии RX (шум при (пере)подключении) остановила DMA-приём | Восстанавливается автоматически (`HAL_UART_ErrorCallback`); если нет — проверить целостность линии PA10 |

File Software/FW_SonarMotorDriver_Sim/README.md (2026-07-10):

# FW_SonarMotorDriver_Sim — имитатор UART-протокола

Отладочная прошивка для STM32F103C8 (та же плата, что и основная). По линии связи
(USART1, PA9 TX / PA10 RX, 115200 8N1) **неотличима от основной прошивки в штатной
работе**: принимает все команды, отвечает теми же строками и шлёт ту же телеметрию.

**Внутри нет реального функционала:**

- нет обмена с энкодером LENZ IRS (SPI/BiSS C не инициализируются);
- нет управления TMC2209 (USART2, TIM4/STEP/DIR не используются; пин ENN = HIGH,
  драйвер принудительно выключен на случай прошивки в реальную плату).

Назначение: отладка ПО верхнего уровня (парсеры телеметрии, GUI, ROS-узлы и т.п.)
без подключённого мотора, энкодера и силового питания.

## Модель движения

Виртуальная позиция движется к цели с ограничением скорости `MAX_SPEED_DEG_S`
(1200°/с), квантуется в микрошаги (256 × 200/об), deadband 0.05° — числа в
телеметрии выглядят как у реального привода в open-loop. При старте позиция
инициализируется значением 37.5° и «уезжает» в 0° — имитация хоминга после сброса.

Телеметрия всегда показывает штатную работу: `ec:0`, режим `m:cl`.

## Отличия от основной прошивки (протокольно незаметные)

| Аспект | Основная | Имитатор |
| --- | --- | --- |
| Позиция `cp` | энкодер BiSS C | виртуальная модель |
| Движение | TMC2209 STEP/DIR + PID | численное интегрирование |
| `kp=/ki=/kd=` | влияют на PID | сохраняются, echo в телеметрии |
| `v=/a=` (скорость/ускорение) | ограничивают контур управления | влияют на модель движения так же |
| `irun/ihold/icur/mstep` | пишутся в чип по UART | сохраняются, отражаются в `mcfg` |
| `ec` (код ошибки) | реальные ошибки BiSS | всегда 0 |
| `m` (режим) | cl/ol по состоянию энкодера | всегда cl |
| Диагностика энкодера (старт и `diag`) | реальная серия чтений BiSS, возможен `err:enc` | всегда `enc:ok n=16/16 spread=0.000` |
| Фильтр выбросов энкодера (`ec:6`, поле `of`) | отбрасывает неправдоподобные показания | нет выбросов, `of:0` |
| Защита от блокировки вала (`err:stall`) | вал стоит ≥1 с при команде движения → драйвер выключается | нет (виртуальный вал не блокируется) |
| SYNC_OUT (PB9) | работает | работает (по модели) |
| IWDG, LED PC13 | работают | работают |

## Структура проекта

```
FW_SonarMotorDriver_Sim/
├── platformio.ini
├── openocd/
│   └── wch-link.cfg       — конфиг адаптера WCH-Link (тот же, что в FW_SonarMotorDriver)
├── include/
│   ├── board.h            — те же константы пинов/скорости/PID (скопирован без изменений)
│   ├── stm32f1xx_hal_conf.h
│   ├── uart.h
│   ├── cmd_parser.h
│   └── line_reader.h
└── src/
    ├── main.c             — модель движения, сканирование, команды, телеметрия (написан для имитатора)
    ├── uart.c             — UART (USART1 PA9/PA10): DMA circular RX + IDLE, DMA TX, автовосстановление RX при ошибке линии
    ├── cmd_parser.c        — тот же парсер команд, что в основной прошивке
    └── line_reader.c
```

Никакого `lib/tmc2209`, `biss_c.*`, `pid.*`, `tools/`, `test/` — в этом проекте нет ни реального драйвера, ни тестов, ни утилит.

## Сборка и прошивка

```bash
pio run                   # сборка
pio run --target upload   # прошивка (WCH-Link, см. platformio.ini)
```

## Проверка

Телеметрия и команды — как в основной прошивке (см.
[../FW_SonarMotorDriver/README.md](../FW_SonarMotorDriver/README.md)):

```
cp:0.01,ec:0            ← телеметрия 250 Гц
> mcfg
mode=STEP_DIR run=600 hold=300 microsteps=256 ready=1
> t=90
ok:t=90.00              ← cp плавно едет к 90
> scan=0,90,10,100
ok:scan=0.00,90.00,10.00,100
> stop
ok:stop
```

Автотест из основного проекта тоже проходит:
`python ../FW_SonarMotorDriver/tools/test_commands.py COM24`.

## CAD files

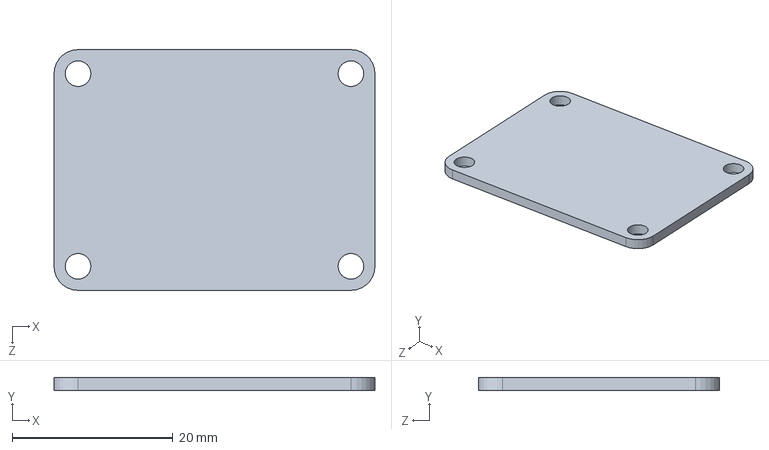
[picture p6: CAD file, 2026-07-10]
Hardware/CAD/Board_40mm_30mm.SLDPRT
40.0 x 1.60 x 30.0 mm

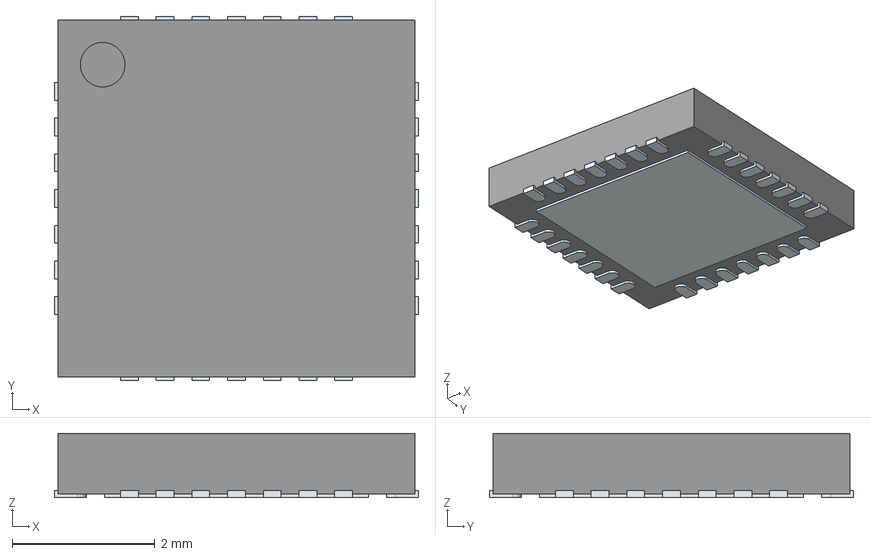
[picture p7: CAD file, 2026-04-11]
Hardware/CAD/BOM/TMC2209-LA-T.stp
5.10 x 5.10 x 0.9 mm
ThermalPin
PinsArrayLR
PinsArrayTB

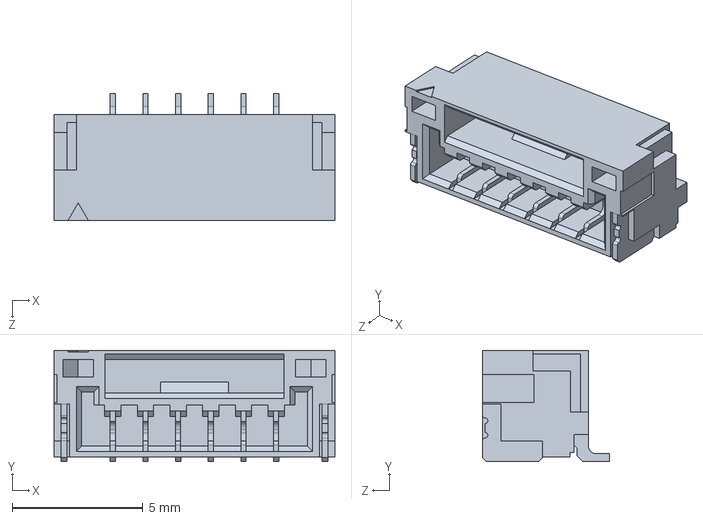
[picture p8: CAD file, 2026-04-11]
Hardware/CAD/BOM/SM06B-GHS-TB_LF__SN_.stp.SLDPRT
10.8 x 4.25 x 4.85 mm

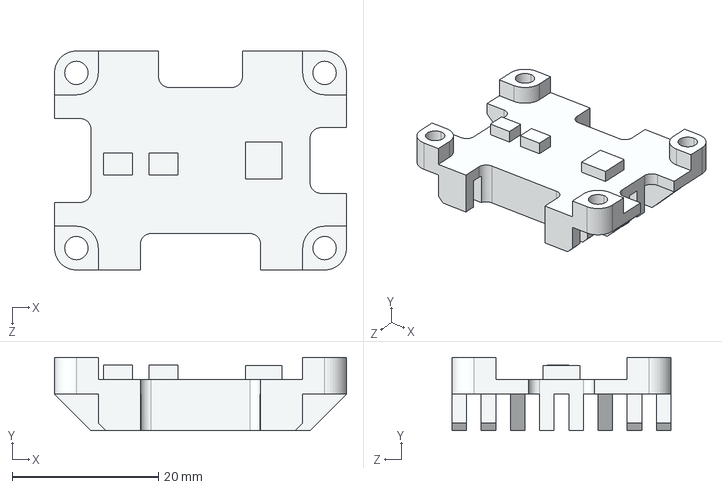
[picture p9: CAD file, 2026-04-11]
Hardware/CAD/Радиатор_1шт.STEP
40.0 x 10.0 x 30.0 mm

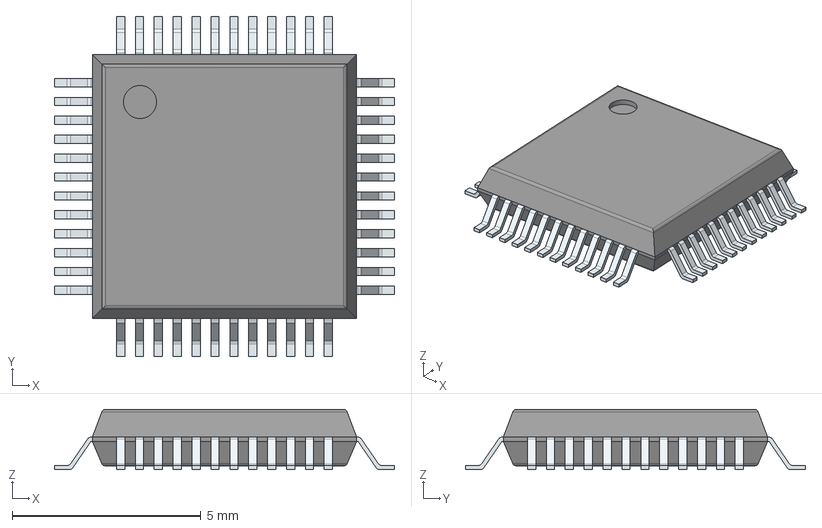
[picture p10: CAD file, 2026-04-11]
Hardware/CAD/BOM/STM32F103C8T6XXX.stp
9.00 x 9.00 x 1.60 mm
PinsArrayLR
PinsArrayTB

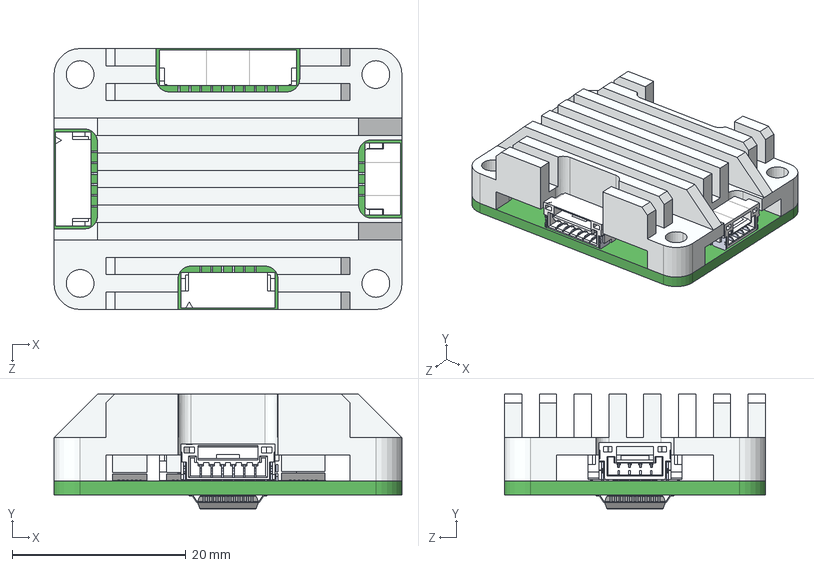
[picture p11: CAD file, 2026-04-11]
Hardware/CAD/Сборка SonarMotorDriver.STEP
40.0 x 13.2 x 30.0 mm
Board_40mm_30mm
SM06B-GHS-TB_LF__SN_.stp x 2
SM10B-GHS-TB.stp
SM04B-GHS-TB_LF__SN_.stp
TMC2209-LA-T
LT3012BEDE#TRPBF x 2
Радиатор
STM32F103C8T6XXX

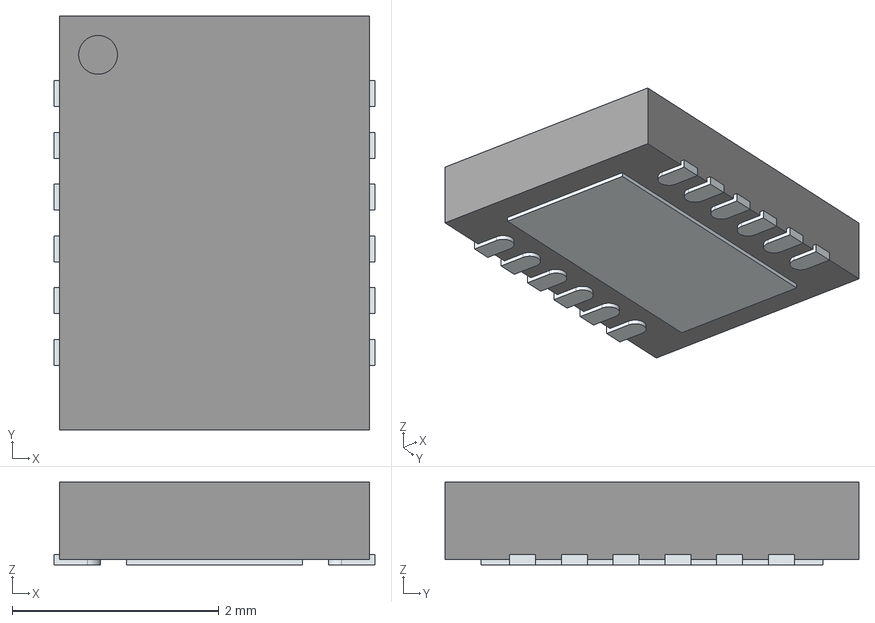
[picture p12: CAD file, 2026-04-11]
Hardware/CAD/BOM/LT3012BEDE#TRPBF.stp
3.10 x 4.00 x 0.8 mm
ThermalPin
PinsArrayLR

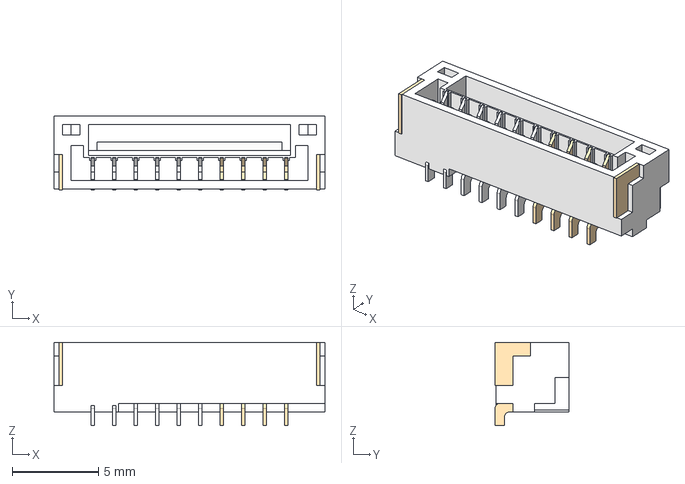
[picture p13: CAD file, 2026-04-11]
Hardware/CAD/BOM/SM10B-GHS-TB.stp
15.8 x 4.30 x 4.85 mm

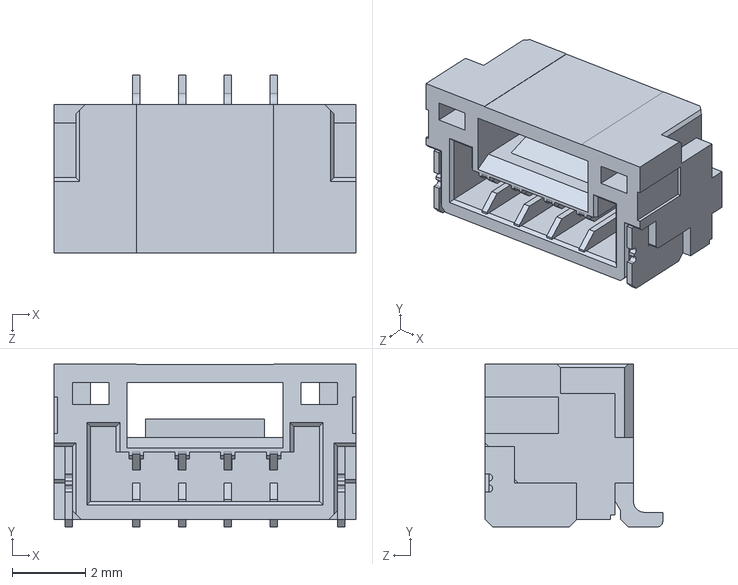
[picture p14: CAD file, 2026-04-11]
Hardware/CAD/BOM/SM04B-GHS-TB_LF__SN_.stp.SLDPRT
8.25 x 4.45 x 4.85 mm

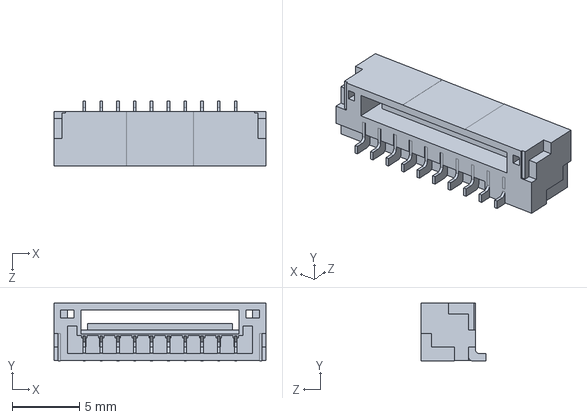
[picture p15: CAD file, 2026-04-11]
Hardware/CAD/BOM/SM10B-GHS-TB.stp.SLDPRT
15.8 x 4.30 x 4.85 mm

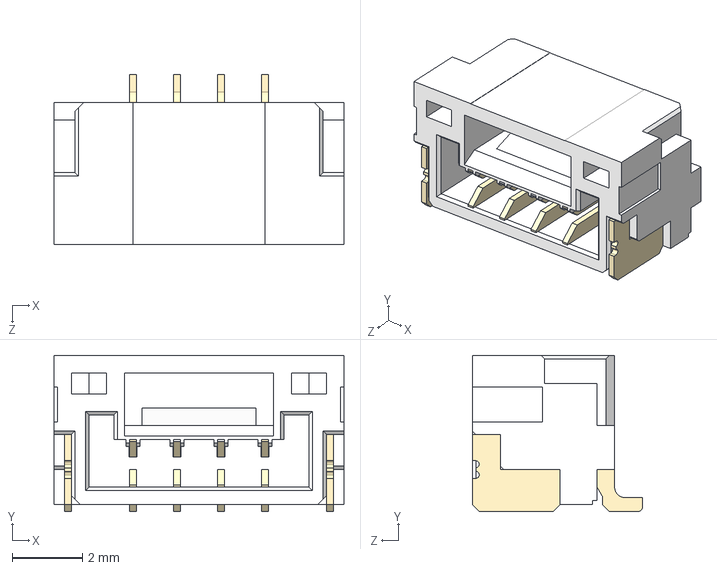
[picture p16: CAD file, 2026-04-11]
Hardware/CAD/BOM/SM04B-GHS-TB_LF__SN_.stp
8.25 x 4.45 x 4.85 mm

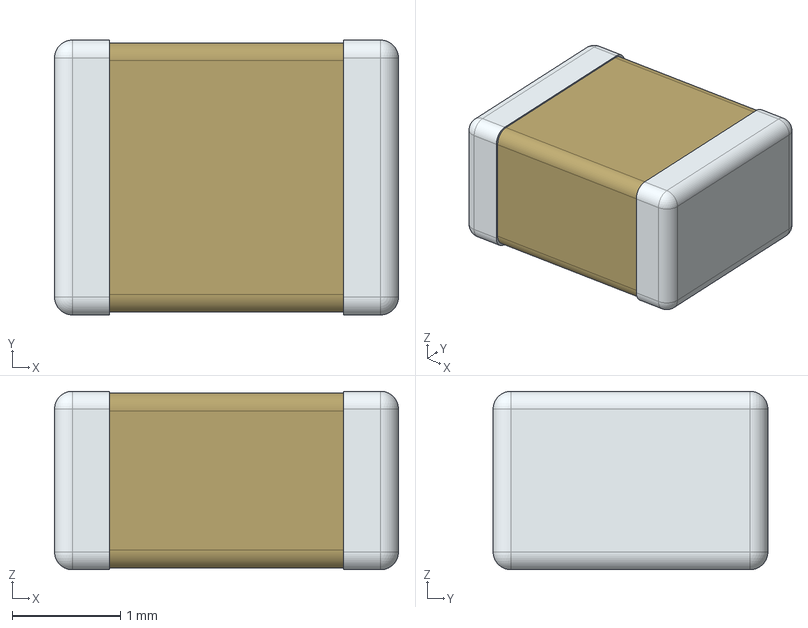
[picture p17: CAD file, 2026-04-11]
Hardware/CAD/BOM/1812B226K250NT.stp
3.18 x 2.54 x 1.65 mm

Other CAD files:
Hardware/CAD/BOM/SM06B-GHS-TB_LF__SN_.stp
Hardware/CAD/Радиатор.SLDPRT
Hardware/CAD/BOM/1812B226K250NT.SLDPRT
Hardware/CAD/BOM/LT3012BEDE#TRPBF.SLDPRT
Hardware/CAD/BOM/STM32F103C8T6XXX.SLDPRT
Hardware/CAD/BOM/TMC2209-LA-T.SLDPRT
Hardware/CAD/Board_40mm_30mm.DXF
Hardware/CAD/Сборка SonarMotorDriver.SLDASM

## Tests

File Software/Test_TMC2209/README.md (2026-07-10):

# Test_TMC2209 — тестовая прошивка TMC2209 + STM32F103C8

Стенд для отладки драйвера шагового двигателя **TMC2209**: инициализация,
вращение мотора, настройка тока/микрошага и чтение диагностических регистров
через текстовый **UART CLI**.

## Аппаратная часть

### MCU

**STM32F103C8** (LQFP-48, «Blue Pill»). Тактирование от внутреннего
генератора **HSI 8 МГц → PLL → SYSCLK 48 МГц** (внешний кварц не требуется).

### Подключение TMC2209

```
STM32F103C8        TMC2209
──────────         ───────
PA2 (USART2_TX) ──┬── PDN_UART    (через R 1 кОм от PA2)
PA3 (USART2_RX) ──┘                (напрямую к PDN_UART)
PB8              ───── STEP
PB7              ───── DIR
PB6              ───── ENN         (LOW = вкл, HIGH = выкл)
```

CLI-терминал подключается к **USART1** через любой USB-UART переходник (3.3 В):

```
STM32F103C8        USB-UART (3.3 В)
──────────         ───────────────
PA9  (USART1_TX) ───── RX          (ответы прошивки в терминал)
PA10 (USART1_RX) ───── TX          (команды с ПК)
GND              ───── GND
```

### Схема подключения UART к TMC2209 (single-wire)

TMC2209 использует **однопроводной UART** на пине PDN_UART.
MCU подключается двумя линиями (TX + RX) к одному пину TMC2209:

```
         1 кОм
PA2 (TX) ──[===]──┬── PDN_UART (TMC2209)
                  │
PA3 (RX) ─────────┘
```

Резистор 1 кОм на TX предотвращает конфликт при одновременной передаче
(MCU TX + ответ TMC2209 на той же линии). RX подключён напрямую.

### Адресация TMC2209

Адрес задаётся пинами MS1/MS2 на TMC2209:

| MS1 | MS2 | Адрес |
|-----|-----|---|
| GND | GND | 0 |
| VCC | GND | 1 |
| GND | VCC | 2 |
| VCC | VCC | 3 |

В прошивке: `TMC2209_UART_ADDR = 0` (MS1=GND, MS2=GND).

### Питание TMC2209

```
         TMC2209
         ┌──────────┐
VM ──────┤ VS       │   Питание мотора: 4.75–29 В
         │          │
VCC_IO ──┤ VCC_IO   │   Логика: 3.3 В (от STM32)
         │          │
GND ─────┤ GND      │
         │          │
    ┌────┤ OA1  OB1 ├────┐
    │    │          │    │   Обмотки шагового
  Motor  │ OA2  OB2 │  Motor  двигателя (A и B)
  Coil A └──────────┘  Coil B
```

**Обязательные конденсаторы:**
- **100–470 мкФ** (электролит, low ESR) между VS и GND — как можно ближе к TMC2209
- **100 нФ** керамика между VS и GND — рядом с микросхемой
- **100 нФ** керамика между VCC_IO и GND
- **2.2 мкФ** между 5VOUT и GND (выход внутреннего регулятора)

> ⚠️ Линию питания VS **всегда** подключайте через электролитический
> конденсатор — иначе выбросы напряжения могут повредить TMC2209.

### Токоизмерительные резисторы (Rsense)

Прошивка настроена на **Rsense = 0.11 Ом** (внешние резисторы).
Устанавливаются между выводами BRA/GND и BRB/GND.

Ток задаётся в `board.h`:
- `TMC2209_IRUN_MA = 800` — ток при движении (мА)
- `TMC2209_IHOLD_MA = 400` — ток удержания (мА)

### Сводная таблица пинов STM32F103C8

| Пин  | Функция | Назначение | Примечание |
|---|---|---|---|
| PA9  | USART1_TX | CLI | Ответы прошивки в терминал |
| PA10 | USART1_RX | CLI | Команды с ПК |
| PA2  | USART2_TX | TMC2209 UART | Через 1 кОм к PDN_UART |
| PA3  | USART2_RX | TMC2209 UART | Напрямую к PDN_UART |
| PB6  | GPIO OUT | TMC2209 ENN | LOW = драйвер вкл |
| PB7  | GPIO OUT | TMC2209 DIR | Направление вращения |
| PB8  | GPIO OUT / TIM4_CH3 (AF)  | TMC2209 STEP | GPIO в UART-режиме, PWM в SD-режиме  |

### Тактирование

```
HSI 8 МГц → /2 → PLL ×12
  SYSCLK = 48 МГц
  AHB    = 48 МГц
  APB1   = 24 МГц  (таймеры APB1 = 48 МГц)
  APB2   = 48 МГц
```

## Прошивка

### Сборка

Требуется [PlatformIO](https://platformio.org/):

```
pio run
```

### Загрузка (WCH-Link / CMSIS-DAP + OpenOCD)

Программатор — WCH-Link (в режиме CMSIS-DAP, SWD). Конфиг адаптера —
`openocd/wch-link.cfg`. Загрузка:

```
pio run -t upload
```

Команда прошивки (уже прописана в `platformio.ini`):

```
openocd -f openocd/wch-link.cfg -f target/stm32f1x.cfg \
        -c "program .pio/build/stm32f103c8/firmware.bin 0x08000000 verify reset" \
        -c "shutdown"
```

### Режимы управления

**UART (по умолчанию)** — TMC2209 использует встроенный генератор шагов.
Скорость задаётся через регистр VACTUAL. Пины STEP/DIR игнорируются.
Знак значения определяет направление.

**STEP/DIR** — MCU генерирует импульсы на пине STEP через TIM4 (PWM).
Пин DIR задаёт направление. VACTUAL = 0, TMC2209 слушает внешние импульсы.

### Команды (CLI-терминал, 115200 8N1)

| Cmd | Описание |
|---|---|
| `h` | Список команд (справка) |
| `i` | Инициализация / переинициализация TMC2209 |
| `m<N>`  | Движение: UART — VACTUAL, STEP/DIR — шагов/сек (знак = направление) |
| `ms<N>` | Микрошаг (1, 2, 4, 8, 16, 32, 64, 128, 256) |
| `ir<N>` | Ток движения, мА |
| `ih<N>` | Ток удержания, мА (≤ тока движения) |
| `s` | Стоп |
| `e` | Включить драйвер (ENN=LOW) |
| `d` | Выключить драйвер (ENN=HIGH) |
| `p` | Режим STEP/DIR |
| `u` | Режим UART |
| `st` | Краткий статус (DRV_STATUS) |
| `t` | Полная телеметрия (GSTAT, IOIN, DRV_STATUS, MSCNT, … все регистры) |
| `v` | Версия IC (ожидается 0x21) |
| `a` | Сканирование адресов 0..3 на шине |
| `r` | Разовое чтение IOIN |
| `diag`  | Конфигурация драйвера + проверка связи (чтение IOIN) |
| `c` | Периодический вывод CS_ACTUAL (тока), останов командой `s` |

### Примеры

```
h              → список команд
v              → IC=0x21 OK
ir600          → irun=600 mA
ms32           → microsteps=32
m500           → UA=500     (UART: VACTUAL=500)
s              → stop
p              → mode:SD    (переключить в STEP/DIR)
m1000          → SD=1000    (1000 шагов/сек вперёд)
m-500          → SD=-500    (500 шагов/сек назад)
s              → stop
u              → mode:UA    (вернуться в UART)
st             → DRV=0x... [UA]
```

### Структура проекта

```
Test_TMC2209/
├── include/
│   └── board.h            — конфигурация пинов, токов, тактирования, таймера
├── src/
│   └── main.c             — main loop, UART CLI, режимы UART / STEP-DIR
├── lib/
│   └── tmc2209/           — кроссплатформенная библиотека драйвера TMC2209
│       ├── include/tmc2209/  — публичный API, карта регистров, типы
│       └── src/              — реализация протокола + порт STM32 HAL
├── openocd/
│   └── wch-link.cfg       — конфиг адаптера WCH-Link (CMSIS-DAP/SWD)
├── docs/
│   ├── TMC2209_API.md     — описание API библиотеки tmc2209
│   └── examples/          — примеры использования библиотеки TMC2209
├── tools/
│   ├── serial_monitor.py  — монитор COM-порта: чтение и проверка телеметрии (регистры GSTAT/IOIN/DRV_STATUS и т.д.)
│   ├── test_commands.py   — автотест всех CLI-команд с логом TX/RX (лог пишется в logs/)
│   └── requirements.txt   — зависимости для скриптов (pyserial)
├── platformio.ini
└── README.md
```

**Автотест и монитор (`tools/`):** требуют `pip install -r tools/requirements.txt`.

```bash
python tools/test_commands.py COM19       # автотест всех команд, лог в logs/
python tools/test_commands.py COM19 --no-test   # только лог TX/RX, без проверок
python tools/serial_monitor.py COM19      # монитор телеметрии (t / c) с проверкой значений
```

### Параметры в board.h

| Параметр | Значение | Описание |
|---|---|---|
| `SYSCLK_HZ` | 48000000 | Тактовая частота, Гц (HSI+PLL) |
| `CLI_UART_BAUDRATE` | 115200 | Скорость CLI (USART1) |
| `TMC2209_UART_BAUDRATE` | 115200 | Скорость UART к TMC2209 (USART2)  |
| `TMC2209_UART_ADDR` | 0 | Адрес (MS1=GND, MS2=GND) |
| `TMC2209_RSENSE_OHM` | 0.11 | Rsense, Ом |
| `TMC2209_IRUN_MA` | 800 | Ток движения, мА |
| `TMC2209_IHOLD_MA` | 400 | Ток удержания, мА |
| `TMC2209_MICROSTEPS` | 16 | Микрошаг (1–256, степень двойки)  |

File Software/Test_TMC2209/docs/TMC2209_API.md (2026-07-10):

# TMC2209 Library — API Reference

> [!IMPORTANT]
> **Питание драйвера (VS):** Линию питания драйвера VS необходимо **ВСЕГДА** подключать с дополнительным электролитическим конденсатором (100–470 мкФ) для стабильной работы и защиты от пробоя.

## 1. Overview

Platform-agnostic C library for Trinamic TMC2209 stepper motor driver (UART interface).

**Core library** (`lib/tmc2209/`) — zero platform dependencies:
- UART protocol (CRC, framing, read/write)
- Blocking init with communication verification
- Shadow registers for write-only register tracking
- Typed config structs for CHOPCONF, PWMCONF, CoolStep, StallGuard
- Motor current, microsteps, VACTUAL velocity control
- Full diagnostic register decoding
- CoolStep adaptive current control
- StallGuard sensorless stall detection
- OTP memory access
- Multi-device UART support
- StealthChop / SpreadCycle presets

**Platform layer** (application code):
- `tmc2209_port_stm32_hal.c` — STM32 HAL callbacks implementation
- STEP/DIR pulse generation (timers, DMA) — not part of library

**Example application**: `src/main.c` — UART CLI demonstrating library usage.

## 2. Quick Start

```c
#include "tmc2209/tmc2209.h"

tmc2209_config_t cfg = TMC2209_DEFAULT_CONFIG;
cfg.addr     = 0;
cfg.rsense   = 0.11f;
cfg.irun_ma  = 800;
cfg.ihold_ma = 400;

tmc2209_io_t io = {
    .uart_tx       = my_uart_tx,
    .uart_rx       = my_uart_rx,
    .uart_rx_flush = my_uart_flush,
    .delay_us      = my_delay_us,
    .set_enable    = my_set_enable,
    .debug_print   = NULL,
    .ctx           = &my_hw,
};

tmc2209_t drv;
tmc2209_result_t res = tmc2209_init(&drv, &cfg, &io);
if (res != TMC2209_OK) { /* handle error */ }

tmc2209_enable(&drv);
tmc2209_set_vactual(&drv, 5000);
```

## 3. Platform Callbacks

All hardware access is routed through `tmc2209_io_t`:

| Callback | Required | Description |
|---|---|---|
| `uart_tx` | Yes | Send bytes. Return 0=OK, non-zero=error |
| `uart_rx` | Yes | Receive bytes. Write count to `*received`. Return 0=all, 1=timeout, <0=error |
| `uart_rx_flush` | Yes | Discard pending RX data, clear UART error flags |
| `delay_us` | Yes | Blocking microsecond delay |
| `set_enable` | Yes | Drive ENN pin: 0=enabled (low), 1=disabled (high) |
| `debug_print` | No | Diagnostic string output (NULL to disable) |
| `ctx` | — | Opaque pointer passed to all callbacks |

## 4. Configuration

### tmc2209_config_t

| Field | Type | Default | Description |
|---|---|---|---|
| `addr` | uint8_t | 0 | UART slave address 0..3 (MS1/MS2 pins) |
| `rsense` | float | 0.11 | Sense resistor, Ohm |
| `irun_ma` | uint16_t | 800 | Run current, mA |
| `ihold_ma` | uint16_t | 400 | Hold current, mA |
| `microsteps` | uint16_t | 16 | 1,2,4,8,16,32,64,128,256 |
| `reply_delay_us` | uint16_t | 500 | Delay after TX before RX |
| `iholddelay` | uint8_t | 4 | Hold current ramp delay 0..15 |
| `senddelay` | uint8_t | 4 | UART reply send delay 0..15 |
| `pwmconf` | uint32_t | 0 | PWMCONF raw value (0=library default) |
| `tpwmthrs` | uint32_t | 0 | TPWMTHRS velocity threshold |
| `tpowerdown` | uint8_t | 20 | Power-down delay 0..255 |
| `en_spreadcycle` | uint8_t | 0 | 0=StealthChop, 1=SpreadCycle |

Use `TMC2209_DEFAULT_CONFIG` for sensible defaults.

## 5. API Reference

### Init / Deinit

| Function | Description |
|---|---|
| `tmc2209_init(drv, cfg, io)` | Full blocking init: GCONF, currents, CHOPCONF, PWMCONF, verify IFCNT+VERSION |
| `tmc2209_deinit(drv)` | Stop motor, disable driver, clear state |

### Low-level Register Access

| Function | Description |
|---|---|
| `tmc2209_read_reg(drv, reg, &value)` | Read register at configured address |
| `tmc2209_write_reg(drv, reg, value)` | Write register at configured address |
| `tmc2209_read_reg_addr(drv, addr, reg, &value)` | Read at arbitrary slave address |

### GCONF

| Function | Description |
|---|---|
| `tmc2209_get_gconf(drv, &gc)` | Read GCONF from chip, decode into `tmc2209_gconf_t` |
| `tmc2209_set_shaft(drv, inverted)` | Invert motor direction (0=normal, 1=inverted) |
| `tmc2209_enable_spreadcycle(drv)` | Switch to SpreadCycle chopper mode |
| `tmc2209_enable_stealthchop(drv)` | Switch to StealthChop PWM mode |
| `tmc2209_enable_internal_rsense(drv, en)` | Enable/disable internal sense resistors |

### Current / Power

| Function | Description |
|---|---|
| `tmc2209_set_current(drv, run_ma, hold_ma)` | Set both currents in mA |
| `tmc2209_set_run_current(drv, run_ma)` | Set run current only |
| `tmc2209_set_hold_current(drv, hold_ma)` | Set hold current only |
| `tmc2209_get_current_config(drv, &cc)` | Read CS values from shadow |
| `tmc2209_set_iholddelay(drv, delay)` | Set hold current transition delay 0..15 |
| `tmc2209_set_tpowerdown(drv, value)` | Set power-down delay 0..255 |

### CHOPCONF

| Function | Description |
|---|---|
| `tmc2209_set_chopconf_config(drv, &cc)` | Set from typed `tmc2209_chopconf_t` |
| `tmc2209_get_chopconf_config(drv, &cc)` | Read from chip into typed struct |
| `tmc2209_set_chopconf(drv, value)` | Set from raw uint32_t |
| `tmc2209_set_microsteps(drv, ms)` | Set microstep resolution (validates input) |
| `tmc2209_get_microsteps(drv, &ms)` | Read current resolution from chip |
| `tmc2209_enable_interpolation(drv, en)` | Enable 256-µstep interpolation |
| `tmc2209_enable_double_edge_step(drv, en)` | Enable both-edge STEP counting |

### PWMCONF

| Function | Description |
|---|---|
| `tmc2209_set_pwmconf_config(drv, &pc)` | Set from typed `tmc2209_pwmconf_t` |
| `tmc2209_get_pwmconf_config(drv, &pc)` | Read from shadow (register is write-only) |
| `tmc2209_set_pwmconf(drv, value)` | Set from raw uint32_t |
| `tmc2209_set_freewheel(drv, mode)` | Set standstill freewheel mode |

### CoolStep

| Function | Description |
|---|---|
| `tmc2209_set_coolstep_config(drv, &cs)` | Configure CoolStep from `tmc2209_coolstep_config_t` |
| `tmc2209_get_coolstep_config(drv, &cs)` | Read from shadow (COOLCONF is write-only) |
| `tmc2209_set_tcoolthrs(drv, threshold)` | Set velocity threshold for CoolStep/StallGuard |

### StallGuard

| Function | Description |
|---|---|
| `tmc2209_set_sgthrs(drv, threshold)` | Set StallGuard threshold 0..255 |
| `tmc2209_get_sgthrs(drv, &threshold)` | Read from shadow (SGTHRS is write-only) |
| `tmc2209_configure_stallguard(drv, &sg)` | Set SGTHRS + TCOOLTHRS together |

### Motor Control

| Function | Description |
|---|---|
| `tmc2209_enable(drv)` | Enable driver (ENN low) |
| `tmc2209_disable(drv)` | Disable driver (ENN high) |
| `tmc2209_set_vactual(drv, velocity)` | Set internal step generator velocity |
| `tmc2209_stop(drv)` | Set VACTUAL=0 |

### Standby

| Function | Description |
|---|---|
| `tmc2209_enter_standby(drv)` | Software standby: stop, disable, zero hold, freewheel |
| `tmc2209_exit_standby(drv)` | Restore previous settings and re-enable |

After standby, all register shadows are preserved. If the chip loses power
during standby, call `tmc2209_init()` instead of `tmc2209_exit_standby()`.

### Diagnostics

| Function | Returns |
|---|---|
| `tmc2209_get_version(drv, &ver)` | IC version from IOIN (expected 0x21) |
| `tmc2209_get_ifcnt(drv, &cnt)` | UART interface counter |
| `tmc2209_get_ioin(drv, &ioin)` | Pin states → `tmc2209_ioin_t` |
| `tmc2209_get_drv_status(drv, &ds)` | Full status → `tmc2209_drv_status_t` |
| `tmc2209_get_gstat(drv, &gs)` | Global status → `tmc2209_gstat_t` |
| `tmc2209_clear_gstat(drv)` | Clear GSTAT flags |
| `tmc2209_get_sg_result(drv, &sg)` | StallGuard result 0..1023 |
| `tmc2209_get_tstep(drv, &tstep)` | Measured step time |
| `tmc2209_get_cs_actual(drv, &cs)` | Actual current scale 0..31 |
| `tmc2209_get_pwm_scale(drv, &ps)` | PWM scaling → `tmc2209_pwm_scale_t` |
| `tmc2209_get_pwm_auto(drv, &pa)` | Auto-tune results → `tmc2209_pwm_auto_t` |
| `tmc2209_get_mscnt(drv, &cnt)` | Microstep counter 0..1023 |
| `tmc2209_get_mscuract(drv, &mc)` | Phase currents → `tmc2209_mscuract_t` |

### OTP (One-Time Programmable)

> **WARNING**: OTP bits can only go 0→1, NEVER back. This is **irreversible**
> and limited to a small number of write cycles. Most applications do NOT
> need OTP. Use only if you need persistent power-on defaults.

| Function | Description |
|---|---|
| `tmc2209_otp_read(drv, &otp)` | Read all 3 OTP bytes (safe, no side effects) |
| `tmc2209_otp_program_bit(drv, byte, bit)` | Program single bit; verifies before/after |

### FACTORY_CONF

| Function | Description |
|---|---|
| `tmc2209_get_factory_conf(drv, &fc)` | Read FCLKTRIM + OTTRIM |
| `tmc2209_set_fclktrim(drv, trim)` | Set clock trim 0..31 (affects UART timing) |

### Multi-device

| Function | Description |
|---|---|
| `tmc2209_scan_bus(drv, results[4])` | Scan addresses 0..3, returns count found |

### Presets

| Function | Description |
|---|---|
| `tmc2209_apply_stealthchop_defaults(drv)` | GCONF + PWMCONF for quiet StealthChop |
| `tmc2209_apply_spreadcycle_defaults(drv)` | GCONF + CHOPCONF for SpreadCycle |

### Utility

| Function | Description |
|---|---|
| `tmc2209_last_error(drv)` | Last transport error code |
| `tmc2209_result_str(res)` | Error code to string |

## 6. Error Codes

All functions return `tmc2209_result_t`:

| Code | String | Meaning |
|---|---|---|
| `TMC2209_OK` | OK | Success |
| `TMC2209_ERR_TIMEOUT` | TIMEOUT | No UART response |
| `TMC2209_ERR_UART` | UART_ERROR | UART callback error |
| `TMC2209_ERR_BAD_FRAME` | BAD_FRAME | Response received but invalid |
| `TMC2209_ERR_CRC` | CRC_ERROR | CRC mismatch |
| `TMC2209_ERR_INVALID_ARG` | INVALID_ARG | NULL pointer or out-of-range parameter |
| `TMC2209_ERR_NOT_INIT` | NOT_INITIALIZED | Driver not initialized |
| `TMC2209_ERR_UNSUPPORTED` | UNSUPPORTED | Feature not available |
| `TMC2209_ERR_HW` | HW_ERROR | Hardware error (wrong VERSION, OTP fail) |

## 7. Shadow Registers

Write-only TMC2209 registers cannot be read back. The library maintains
shadow copies in `tmc2209_t.shadow` for these registers:

| Register | Shadow field | Access |
|---|---|---|
| GCONF | `shadow.gconf` | R/W (also readable from chip) |
| SLAVECONF | `shadow.slaveconf` | W only |
| IHOLD_IRUN | `shadow.ihold_irun` | W only |
| TPOWERDOWN | `shadow.tpowerdown` | W only |
| TPWMTHRS | `shadow.tpwmthrs` | W only |
| TCOOLTHRS | `shadow.tcoolthrs` | W only |
| VACTUAL | `shadow.vactual` | W only |
| SGTHRS | `shadow.sgthrs` | W only |
| COOLCONF | `shadow.coolconf` | W only |
| CHOPCONF | `shadow.chopconf` | R/W (synced on read) |
| PWMCONF | `shadow.pwmconf` | W only |
| FACTORY_CONF | `shadow.factory_conf` | R/W (synced on read) |

Shadows are populated during `tmc2209_init()`. Typed `set_*` functions
update the shadow atomically: modify → write → update shadow on success.

After a chip power-cycle or reset, call `tmc2209_init()` to re-sync.

## 8. Typed Config Structs

### tmc2209_chopconf_t

| Field | Range | Description |
|---|---|---|
| `toff` | 0..15 | Off-time (0=driver disabled, 1..15 = enabled) |
| `hstrt` | 0..7 | Hysteresis start value |
| `hend` | 0..15 | Hysteresis end value (offset -3 → actual -3..12) |
| `tbl` | 0..3 | Comparator blank time (16/24/36/54 clocks) |
| `vsense` | 0/1 | 0=low sensitivity (higher current range), 1=high |
| `mres` | 0..8 | Microstep resolution (0=256, 1=128, ..., 8=fullstep) |
| `intpol` | 0/1 | Interpolate to 256 microsteps |
| `dedge` | 0/1 | Count both STEP edges |
| `diss2g` | 0/1 | Disable short-to-GND protection |
| `diss2vs` | 0/1 | Disable short-to-VS protection |

### tmc2209_pwmconf_t

| Field | Range | Description |
|---|---|---|
| `pwm_ofs` | 0..255 | User-defined PWM amplitude offset |
| `pwm_grad` | 0..255 | Velocity-dependent PWM gradient |
| `pwm_freq` | 0..3 | PWM frequency (0=2/1024, 1=2/683, 2=2/512, 3=2/410 fclk) |
| `pwm_autoscale` | 0/1 | Enable automatic current scaling |
| `pwm_autograd` | 0/1 | Enable automatic gradient adaptation |
| `freewheel` | 0..3 | Standstill mode: 0=normal, 1=freewheel, 2=LS short, 3=HS short |
| `pwm_reg` | 0..15 | Regulation loop gradient |
| `pwm_lim` | 0..15 | PWM limit for switching back to fullstep |

### tmc2209_coolstep_config_t

| Field | Range | Description |
|---|---|---|
| `semin` | 0..15 | Minimum SG value to enable CoolStep (0=off) |
| `seup` | 0..3 | Current increment step (0=1, 1=2, 2=4, 3=8) |
| `semax` | 0..15 | Hysteresis for CoolStep upper threshold |
| `sedn` | 0..3 | Current decrement speed (0..3) |
| `seimin` | 0/1 | Minimum current: 0=half CS_ACTUAL, 1=quarter |

### tmc2209_drv_status_t

| Field | Description |
|---|---|
| `otpw` | Over-temperature pre-warning (>120°C) |
| `ot` | Over-temperature shutdown (>150°C) |
| `s2ga/s2gb` | Short to GND detected (phase A/B) |
| `s2vsa/s2vsb` | Short to supply detected (phase A/B) |
| `ola/olb` | Open load detected (phase A/B) |
| `t120..t157` | Temperature threshold flags |
| `cs_actual` | Actual motor current scale 0..31 |
| `stealth` | StealthChop mode active |
| `stst` | Motor standstill detected |

## 9. Limitations and Caveats

- **OTP is irreversible.** Bits go 0→1 only, limited write cycles.
- **Standby/reset** requires `tmc2209_init()` to re-synchronize all registers.
- **DIAG/INDEX pin** behavior depends on board wiring. The library can configure
  `index_otpw` and `index_step` via GCONF, but the pin must be physically connected.
- **Internal Rsense** changes current scaling dramatically. Only enable when motor
  is disabled. Not all boards support this.
- **STEP/DIR mode** is not part of this library — it depends on platform timers.
- **Not thread-safe.** The debug buffer is static/shared. Do not call library
  functions from multiple threads without external synchronization.
- **FACTORY_CONF FCLKTRIM** affects the internal oscillator frequency. Changing it
  may affect UART timing if using internal clock. Modify only if you understand
  the implications.
- **Sensorless homing** via StallGuard requires DIAG pin connected to a controller
  input and appropriate TCOOLTHRS/SGTHRS tuning at the target velocity.

## 10. File Structure

```
lib/tmc2209/
├── include/tmc2209/
│   ├── tmc2209.h          ← public API + driver context
│   ├── tmc2209_types.h    ← result codes, configs, decoded register structs
│   ├── tmc2209_regs.h     ← register addresses and bitfield macros
│   └── tmc2209_port.h     ← platform I/O callback interface
├── src/
│   └── tmc2209.c          ← core implementation
└── library.json

docs/
├── TMC2209_API.md          ← this file
└── examples/
    ├── 01_basic_init.c
    ├── 02_motion_vactual.c
    ├── 03_diagnostics.c
    ├── 04_coolstep_stallguard.c
    ├── 05_multi_device.c
    └── 06_otp_advanced.c
```

## 11. Porting to a New Platform

1. Implement 5 callbacks in `tmc2209_io_t` for your hardware
2. Fill `tmc2209_config_t` with your motor parameters
3. Call `tmc2209_init()` — done

No `#define` board macros, no global state, no compile-time platform selection.
The entire platform dependency is isolated in the callback struct.

See `tmc2209_port_stm32_hal.c` for a complete STM32 HAL reference implementation.

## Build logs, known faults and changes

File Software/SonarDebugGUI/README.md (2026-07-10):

# SonarDebugGUI — отладчик FW_SonarMotorDriver

Графическое приложение (PySide6, тёмная тема) для проверки **всего функционала**
основной прошивки [FW_SonarMotorDriver](../FW_SonarMotorDriver): управление мотором,
PID, токи/микрошаг, сканирование, живая телеметрия и **2D сонарная диаграмма (PPI)**
положения гидроакустической антенны.

Работает как с реальной платой (USB-UART, 115200 8N1), так и со **встроенным
симулятором прошивки** — то есть полностью без железа.

схема <!-- при желании добавьте скриншот -->

## Возможности

- **Полное покрытие протокола**: одна кнопка/поле на каждую команду
  (`en/dis/stop`, `t=<°>`, `t=+/t=-`, `v`/`a` — скорость/ускорение, `kp/ki/kd`,
  `op`, `debug`, `scan=…`, `irun/ihold/icur`, `mstep`, `mcfg`, `diag`)
  и один виджет на каждое поле телеметрии.
- **Кнопки быстрого и медленного джога**: удержание — вращение с пресетом
  скорости (1200 / 30 °/с), отпускание — стоп и возврат настроенной скорости.
- **PPI-диаграмма**: луч текущего угла (`cp`), призрак цели (`tp`), сектор скана,
  послесвечение-«свип», цветовая индикация режима (cl/ol) и ошибки энкодера (`ec`).
- **Живые графики** телеметрии (cp/tp/pe/u) с паузой, очисткой и экспортом в CSV.
- **Встроенный симулятор** прошивки: те же строки ответов и телеметрии, что у железа.
- **Консоль** для сырых команд + журнал TX/RX (дублируется в `logs/`).
- **Защита от «молчания» прошивки**: аргументы вне диапазона отсекаются на клиенте,
  а на команды без ответа срабатывает таймаут-предупреждение.

## Установка

Требуется Python 3.10+.

```
cd Software/SonarDebugGUI
pip install -r requirements.txt
```

Зависимости: `PySide6`, `pyqtgraph`, `pyserial` (первая установка объёмная).

## Запуск

```
python run.py
```

### Без железа (симулятор)
1. Выберите «Симулятор» → «Подключить».
2. Пойдёт поток телеметрии, стрелка на диаграмме оживёт.
3. Пробуйте: `Перейти` на угол, толчки CW/CCW, `Старт скана`, PID, токи, `mcfg`.

### С реальной платой
1. Подключите USB-UART адаптер к плате: **PA9 (TX) → RX**, **PA10 (RX) → TX**, **GND**.
2. Выберите «Реальный COM», порт определяется автоматически (кнопка ⟳ — обновить).
3. «Подключить» (115200 8N1).

> Совет: можно прошить [FW_SonarMotorDriver_Sim](../FW_SonarMotorDriver_Sim) —
> отладочную прошивку, которая отвечает тем же протоколом без мотора и энкодера.

## Диаграмма антенны

Прошивка отдаёт угол вала `cp` в градусах. Реального редуктора между валом и антенной
в прошивке нет, поэтому пересчёт задаётся в панели «Диаграмма антенны»:

```
угол_антенны = sign · (cp · масштаб) + смещение_нуля
```

## Структура

```
SonarDebugGUI/
├── run.py                     — запуск
├── requirements.txt
└── sonar_gui/
    ├── app.py                 — QApplication + тема + окно
    ├── main_window.py         — сборка и связи всех виджетов
    ├── protocol.py            — единый источник правды: команды/телеметрия/константы
    ├── controller.py          — DeviceClient: валидация, таймаут ответа, маршрутизация
    ├── simulator.py           — Python-модель прошивки (без Qt)
    ├── logger.py              — журнал TX/RX в logs/
    ├── theme.py, dark.qss     — тёмная тема
    ├── transport/             — Transport: SerialTransport (COM) и SimTransport (симулятор)
    └── widgets/               — PPI-диаграмма, графики и панели управления
```

## Соответствие протоколу

Форматы команд и телеметрии повторяют прошивку (`FW_SonarMotorDriver/src/main.c`,
`cmd_parser.c`). Автотест-эталон из `FW_SonarMotorDriver/tools/test_commands.py`
использует тот же набор команд.

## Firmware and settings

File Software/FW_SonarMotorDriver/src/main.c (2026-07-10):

/**
 * @file main.c
 * @brief Основной модуль приложения. Координация работы всех подсистем.
 *
 * Модуль реализует:
 * - Инициализацию аппаратной части и программных модулей (неблокирующая стейт-машина).
 * - Стартовую диагностику энкодера ДО разрешения движения (серия чтений BiSS-C:
 *   доля валидных ответов + разброс позиции; при провале мотор остаётся выключенным,
 *   хост получает err:enc, при успехе — enc:ok и штатный выход в «дом»).
 * - Главный цикл управления (Control Loop, 1 кГц по TIM2): опрос энкодера, PID, мотор.
 * - STEP/DIR: непрерывная частота (TIM4 PWM), без перезапуска каждый тик — нет рывков.
 * - Защиту от блокировки вала: команда есть, вал по энкодеру стоит дольше
 *   STALL_TIMEOUT_MS — драйвер выключается, хост получает err:stall.
 * - Обработку команд пользователя через UART.
 * - Периодический вывод телеметрии.
 * - Логику автоматического сканирования секторов.
 */

#include "stm32f1xx_hal.h"
#include "board.h"
#include "biss_c.h"
#include "tmc2209/tmc2209_motor.h"
#include "tmc2209/tmc2209_port_stm32_hal.h"
#include "pid.h"
#include "cmd_parser.h"
#include "uart.h"
#include <stdio.h>
#include <stdarg.h>
#include <string.h>
#include <math.h>

/* --- Прототипы --- */

static void SystemClock_Config(void);
static void BSP_Init(void);
static void PollTimer_Init(void);
static void Sample_ISR(void);
static void ProcessCommand(const Cmd_Result *cmd);
static void SendResponse(const char *fmt, ...);
static void PollCommands(void);
static void Encoder_Accumulate(const BiSS_Reading *rd);
static uint8_t Encoder_FilterOutlier(const BiSS_Reading *rd);
static void Mode_Update(uint8_t enc_ok);
static void MotorControl_Tick(uint8_t enc_ok);
static void Stall_Tick(uint8_t enc_ok);
static void Telemetry_Tick(uint8_t enc_ok, BiSS_Status st);
static void Heartbeat_Tick(void);
static void Scan_Tick(void);

/* --- Константы --- */

#define DEG_PER_STEP     (360.0f / (float)MOTOR_STEPS_PER_REV)
#define MAX_DEG_PER_TICK ((float)MAX_SPEED_DEG_S / (float)POLL_FREQ_HZ)
#define DT_S             (1.0f / (float)POLL_FREQ_HZ)
#define COUNTS_TO_DEG(c) ((float)(c) * 360.0f / (float)ENCODER_COUNTS_REV)

/* Тиков опроса до принудительного прерывания зависшего DMA-чтения BiSS */
#define BISS_DMA_TIMEOUT_TICKS \
    ((BISS_DMA_TIMEOUT_MS + POLL_INTERVAL_MS - 1U) / POLL_INTERVAL_MS)

/* Тиков коастинга в CL без данных энкодера до остановки мотора */
#define ENCODER_COAST_TICKS  (ENCODER_COAST_MS / POLL_INTERVAL_MS)

/* Окна детектора блокировки вала в тиках опроса */
#define STALL_TIMEOUT_TICKS    (STALL_TIMEOUT_MS / POLL_INTERVAL_MS)
#define STALL_FAST_TICKS       (STALL_FAST_MS / POLL_INTERVAL_MS)
#define STALL_IDLE_RESET_TICKS (STALL_IDLE_RESET_MS / POLL_INTERVAL_MS)

static inline int32_t DegToSteps(float deg)
{ return (int32_t)(deg / DEG_PER_STEP); }

static inline float clampf(float v, float lo, float hi)
{ return (v < lo) ? lo : (v > hi) ? hi : v; }

static inline int32_t clampi(int32_t v, int32_t lo, int32_t hi)
{ return (v < lo) ? lo : (v > hi) ? hi : v; }

static inline float shortest_path_err(float target, float pos)
{
    float err = target - pos;
    while (err > 180.0f)   err -= 360.0f;
    while (err <= -180.0f) err += 360.0f;
    return err;
}

/* Разность позиций энкодера a - b (в отсчётах) с учётом перехода через ноль */
static inline int32_t enc_wrap_delta(uint32_t a, uint32_t b)
{
    int32_t d = (int32_t)a - (int32_t)b;
    if (d >  (int32_t)(ENCODER_COUNTS_REV / 2)) d -= (int32_t)ENCODER_COUNTS_REV;
    if (d < -(int32_t)(ENCODER_COUNTS_REV / 2)) d += (int32_t)ENCODER_COUNTS_REV;
    return d;
}

/* --- Периферия --- */

static TIM_HandleTypeDef  htim_poll;
static IWDG_HandleTypeDef hiwdg;

/* --- DWT-задержки (блокирующие, для HAL) --- */

#define DWT_MS_CYCLES(ms) ((uint32_t)(ms) * (SYSCLK_HZ / 1000U))

void Delay_Init(void)
{
    CoreDebug->DEMCR |= CoreDebug_DEMCR_TRCENA_Msk;
    DWT->CYCCNT = 0;
    DWT->CTRL  |= DWT_CTRL_CYCCNTENA_Msk;
}

void Delay_ms(uint32_t ms)
{
    while (ms > 0) {
        uint32_t chunk = (ms > 89000U) ? 89000U : ms;
        uint32_t start = DWT->CYCCNT;
        while ((DWT->CYCCNT - start) < DWT_MS_CYCLES(chunk)) ;
        ms -= chunk;
    }
}

/**
 * @brief Состояния неблокирующей инициализации.
 */
typedef enum {
    INIT_UART,          ///< Инициализация командного порта USART1
    INIT_BISS_INIT,     ///< Настройка интерфейса энкодера
    INIT_BISS_WAIT,     ///< Ожидание готовности энкодера после подачи питания
    INIT_ENC_DIAG,      ///< Диагностика энкодера перед разрешением движения
    INIT_MOTOR_DRIVER,  ///< Инициализация фасада управления мотором (TMC2209)
    INIT_POLL_TIMER,    ///< Запуск системного таймера опроса (1 кГц)
    INIT_IWDG,          ///< Запуск сторожевого таймера
    INIT_DONE           ///< Инициализация завершена
} InitState;

static InitState s_init = INIT_UART;
static uint32_t  s_init_t0;

/**
 * @brief Диагностика энкодера: серия чтений BiSS-C (см. board.h ENCODER_DIAG_*).
 *
 * Проверка «здоровья» энкодера: достаточное число валидных ответов и малый
 * разброс позиции при неподвижном вале. Используется дважды:
 * - при старте (до включения мотора): при провале мотор остаётся выключенным,
 *   хост получает err:enc, хоуминг запрещён;
 * - по команде diag: свежая серия собирается на фоне штатного 1 кГц опроса.
 */
typedef struct {
    uint8_t      active;      ///< 1 = сбор образцов ещё идёт
    uint8_t      passed;      ///< 1 = энкодер прошёл проверку
    uint8_t      samples;     ///< Выполнено чтений
    uint8_t      ok_cnt;      ///< Из них валидных (BISS_OK / BISS_ERR_WARNING)
    BiSS_Status  last_st;     ///< Статус последнего чтения
    float        spread_deg;  ///< Разброс позиции по валидным чтениям, град
    BiSS_Reading last_good;   ///< Последнее валидное чтение (якорь позиции)
    /* Накопители разброса (в отсчётах, относительно первого валидного чтения) */
    int32_t      ref, min, max;
    uint8_t      have_ref;
} EncDiag;

static EncDiag g_enc_diag = { .passed = 0, .last_st = BISS_ERR_SPI }; ///< Стартовая
static EncDiag g_rediag;                                              ///< По команде diag

static void EncDiag_Begin(EncDiag *d)
{
    *d = (EncDiag){ .active = 1, .last_st = BISS_ERR_SPI };
}

/**
 * @brief Учёт одного чтения в серии диагностики.
 * @param[in] st Статус чтения.
 * @param[in] rd Данные чтения (используются только при валидном статусе).
 *
 * После ENCODER_DIAG_SAMPLES чтений вычисляет разброс и вердикт (поле passed),
 * сбрасывая active.
 */
static void EncDiag_Sample(EncDiag *d, BiSS_Status st, const BiSS_Reading *rd)
{
    d->samples++;
    d->last_st = st;

    if (st == BISS_OK || st == BISS_ERR_WARNING) {
        d->ok_cnt++;
        d->last_good = *rd;
        /* Разброс позиции с учётом перехода через ноль счётчика энкодера */
        if (!d->have_ref) {
            d->have_ref = 1;
            d->ref = (int32_t)rd->position;
            d->min = d->max = 0;
        } else {
            int32_t delta = enc_wrap_delta(rd->position, (uint32_t)d->ref);
            if (delta < d->min) d->min = delta;
            if (delta > d->max) d->max = delta;
        }
    }

    if (d->samples < ENCODER_DIAG_SAMPLES)
        return;

    d->active     = 0;
    d->spread_deg = COUNTS_TO_DEG(d->max - d->min);
    d->passed     = (d->ok_cnt >= ENCODER_DIAG_MIN_OK) &&
                    (d->spread_deg <= ENCODER_DIAG_MAX_SPREAD_DEG);
}

static void EncDiag_Report(const EncDiag *d)
{
    if (d->passed)
        SendResponse("enc:ok n=%u/%u spread=%.3f pos=%.2f\r\n",
                     (unsigned)d->ok_cnt, (unsigned)d->samples,
                     (double)d->spread_deg, (double)d->last_good.angle_deg);
    else
        SendResponse("err:enc n=%u/%u spread=%.3f last=%u\r\n",
                     (unsigned)d->ok_cnt, (unsigned)d->samples,
                     (double)d->spread_deg, (unsigned)d->last_st);
}

/**
 * @brief Подкормка повторной диагностики (команда diag) чтениями штатного опроса.
 *
 * Образцы собираются из того же 1 кГц цикла, движение не прерывается
 * (запуск diag разрешён только при остановленном моторе). По завершении
 * серии отчёт уходит хосту той же строкой enc:ok / err:enc, что и при старте.
 */
static void Rediag_Feed(BiSS_Status st, const BiSS_Reading *rd)
{
    if (!g_rediag.active)
        return;
    EncDiag_Sample(&g_rediag, st, rd);
    if (!g_rediag.active)
        EncDiag_Report(&g_rediag);
}

/**
 * @brief Опрос стейт-машины инициализации.
 * @return 1, если инициализация завершена, иначе 0.
 *
 * Функция вызывается в цикле до тех пор, пока не будут настроены все модули.
 * Использует DWT-таймер для неблокирующих задержек.
 */
static uint8_t Init_Poll(void)
{
    switch (s_init) {

    case INIT_UART:
        if (UART_Init() == 0)
            s_init = INIT_BISS_INIT;
        break;

    case INIT_BISS_INIT: {
        BiSS_Config cfg = {
            .spi_instance    = SPI1,
            .resolution_bits = ENCODER_RESOLUTION_BITS,
            .de_port = XCVR_DE_PORT, .de_pin = XCVR_DE_PIN,
            .re_port = XCVR_RE_PORT, .re_pin = XCVR_RE_PIN,
        };
        BiSS_Init(&cfg);
        s_init_t0 = DWT->CYCCNT;
        s_init = INIT_BISS_WAIT;
        break;
    }

    case INIT_BISS_WAIT:
        if ((DWT->CYCCNT - s_init_t0) >= DWT_MS_CYCLES(ENCODER_STARTUP_MS)) {
            EncDiag_Begin(&g_enc_diag);
            s_init_t0 = DWT->CYCCNT;
            s_init = INIT_ENC_DIAG;
        }
        break;

    case INIT_ENC_DIAG: {
        /* Серия чтений с паузами: проверяем стабильность энкодера ДО включения мотора */
        if ((DWT->CYCCNT - s_init_t0) < DWT_MS_CYCLES(ENCODER_DIAG_INTERVAL_MS))
            break;
        s_init_t0 = DWT->CYCCNT;

        BiSS_Reading rd;
        EncDiag_Sample(&g_enc_diag, BiSS_Read(&rd), &rd);
        if (g_enc_diag.active)
            break;

        EncDiag_Report(&g_enc_diag);
        s_init = INIT_MOTOR_DRIVER;
        break;
    }

    case INIT_MOTOR_DRIVER: {
        int r = tmc2209_motor_init();
        if (r != 0) {
            SendResponse("err:motor_init=%d\r\n", r);
        }
        s_init = INIT_POLL_TIMER;
        break;
    }

    case INIT_POLL_TIMER:
        PollTimer_Init();
        /* Чистим флаг обновления от Base_Init (EGR UG), иначе ISR сработает сразу */
        __HAL_TIM_CLEAR_FLAG(&htim_poll, TIM_FLAG_UPDATE);
        HAL_TIM_Base_Start_IT(&htim_poll);
        s_init = INIT_IWDG;
        break;

    case INIT_IWDG:
        hiwdg.Instance       = IWDG;
        hiwdg.Init.Prescaler = IWDG_PRESCALER;
        hiwdg.Init.Reload    = IWDG_RELOAD;
        HAL_IWDG_Init(&hiwdg);
        s_init = INIT_DONE;
        break;

    case INIT_DONE:
        return 1;
    }
    return 0;
}

/**
 * @brief Глобальное состояние системы.
 */
typedef enum { 
    MODE_CL = 0,    ///< Closed-Loop: PID-регулирование по энкодеру
    MODE_OL = 1     ///< Open-Loop: прямое управление без ОС (счётчик шагов)
} CtrlMode;

/* Состояние PID-регулятора */
static PID_State g_pid = {
    .kp = PID_KP_DEFAULT, .ki = PID_KI_DEFAULT, .kd = PID_KD_DEFAULT,
    .integral = 0, .prev_error = 0,
    .output_min = -MAX_DEG_PER_TICK, .output_max = MAX_DEG_PER_TICK,
    .initialized = 0
};

static float    g_target_deg     = 0;           ///< Целевая позиция (градусы)
static uint8_t  g_enabled        = 1;           ///< Флаг разрешения работы (движение разрешено)
static uint16_t g_output_period  = OUTPUT_PERIOD_MS_DEFAULT; ///< Период телеметрии
static uint8_t  g_telem_debug    = TELEMETRY_DEBUG_DEFAULT;  ///< Флаг расширенной телеметрии

static uint32_t g_enc_raw_prev   = 0xFFFFFFFF;  ///< Предыдущее "сырое" значение энкодера (для дельты)
static int64_t  g_enc_counts     = 0;           ///< Накопленный счетчик импульсов (многооборотность)

static float    g_cl_accum       = 0;           ///< Накопитель дробных шагов для Closed-Loop
static float    g_ol_accum       = 0;           ///< Накопитель дробных шагов для Open-Loop
static float    g_last_ctrl      = 0;           ///< Последнее вычисленное управляющее воздействие

static CtrlMode g_mode           = MODE_CL;     ///< Текущий режим управления
static uint32_t g_enc_fail_cnt   = 0;           ///< Счетчик пропусков данных энкодера
static uint8_t  g_enc_outlier    = 0;           ///< Последнее чтение отброшено фильтром выбросов
static uint32_t g_outlier_cnt    = 0;           ///< Всего отфильтровано выбросов (телеметрия of)
static uint32_t g_sample_t       = 0;           ///< DWT-момент сэмпла обрабатываемого чтения (фильтр выбросов)
static float    g_ol_pos         = 0;           ///< Виртуальная позиция для Open-Loop
static uint8_t  g_was_outside_db = 0;           ///< Флаг выхода из мертвой зоны (для логики доводки)
static uint8_t  g_homing         = 0;           ///< Флаг процесса выхода в "дом" после инициализации

static int8_t   g_cont_dir       = 0;           ///< Направление непрерывного вращения (t+/t-)

/* --- Профиль движения (команды v= и a=) --- */

static float    g_vmax_deg_s     = SPEED_DEFAULT_DEG_S; ///< Предел скорости, град/с
static float    g_accel_deg_s2   = ACCEL_DEFAULT_DEG_S2;///< Предел ускорения, град/с² (0 = выкл)
static float    g_vel_cmd        = 0;           ///< Текущая слew-скорость, град/тик

static inline float vmax_per_tick(void)
{ return g_vmax_deg_s * DT_S; }
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
int main(void)
{
    HAL_Init();
    SystemClock_Config();
    BSP_Init();
    Delay_Init();

    BiSS_Status  st        = BISS_ERR_SPI;
    uint8_t      enc_ok    = 0;
    uint8_t      init_done = 0;

    while (1) {
        if (!init_done) {
            if (Init_Poll()) {
                if (g_enc_diag.passed) {
                    /* Якорь позиции — последнее валидное чтение диагностики */
                    st = g_enc_diag.last_good.status;
                    Encoder_Accumulate(&g_enc_diag.last_good);
                } else {
                    /* Диагностика не пройдена: мотор не включаем, хоуминг
                     * запрещён (см. Encoder_Accumulate) — ждём оператора. */
                    st = g_enc_diag.last_st;
                    g_enabled = 0;
                }
                /* Первое чтение стартует уже ISR TIM2 (включён в INIT_POLL_TIMER) */
                enc_ok    = (g_enc_raw_prev != 0xFFFFFFFF);
                init_done = 1;
                if (g_enabled) tmc2209_motor_set_enabled(1);
            }
            UART_Task();
            continue;
        }

        UART_Task();
        /* Диагностика TMC2209 — блокирующий UART-обмен: разрешаем его только
         * в простое (не во время сканирования/вращения). Непрерывный STEP-
         * генератор при этом продолжает крутиться на текущей частоте, а
         * сэмплирование энкодера идёт в ISR TIM2 — блокировка цикла не рвёт
         * ни поток импульсов, ни интервал сэмпла. */
        if (g_scan_st == SCAN_IDLE && g_cont_dir == 0)
            tmc2209_motor_task();
        PollCommands();

        if (!s_tick_ready)
            continue;

        /* Снимок результата сэмплирования из ISR (короткая критическая секция) */
        BiSS_Reading rd;
        BiSS_Status  st_new;
        uint8_t      have_new, start_fail;
        __disable_irq();
        rd           = s_sample_rd;
        st_new       = s_sample_st;
        g_sample_t   = s_sample_t;
        have_new     = s_sample_new;   s_sample_new  = 0;
        start_fail   = s_sample_fail;  s_sample_fail = 0;
        s_tick_ready = 0;
        __enable_irq();

        if (have_new) {
            st = st_new;
            enc_ok = (st == BISS_OK || st == BISS_ERR_WARNING);
            g_enc_outlier = 0;
            if (enc_ok && !Encoder_FilterOutlier(&rd)) {
                /* Показание физически невозможно — отброшено как выброс */
                enc_ok        = 0;
                g_enc_outlier = 1;
            }
            if (enc_ok) Encoder_Accumulate(&rd);
            Rediag_Feed(st, &rd);
        } else {
            /* Свежих данных в этом тике нет (обмен ещё в полёте) */
            enc_ok = 0;
        }
        if (start_fail) {
            /* SPI не стартовал — для diag это тоже результат (ошибка) */
            BiSS_Reading dummy = {0};
            Rediag_Feed(BISS_ERR_SPI, &dummy);
        }

        Mode_Update(enc_ok);
        MotorControl_Tick(enc_ok);
        Stall_Tick(enc_ok);
        Scan_Tick();
        Telemetry_Tick(enc_ok, st);
        Heartbeat_Tick();
        HAL_IWDG_Refresh(&hiwdg);
    }
}

/* --- Многооборотная позиция --- */

/**
 * @brief Обработка данных энкодера и расчет многооборотной позиции.
 * @param[in] rd Текущее чтение с энкодера (уже прошедшее фильтр выбросов).
 *
 * Вычисляет разность между текущим и предыдущим значением с учетом переполнения
 * (rollover) 17-битного счетчика. При первом вызове производит привязку позиции
 * и расчет целевой точки для плавного старта.
 */
static void Encoder_Accumulate(const BiSS_Reading *rd)
{
    if (g_enc_raw_prev == 0xFFFFFFFF) {
        g_enc_counts   = (int64_t)rd->position;
        g_enc_raw_prev = rd->position;
        float pos = COUNTS_TO_DEG(g_enc_counts);
        g_ol_pos = pos;
        if (g_enc_diag.passed) {
            /* Автоматический выход в «дом» разрешён только после успешной
             * стартовой диагностики энкодера. */
            g_target_deg = pos + shortest_path_err(STARTUP_TARGET_OFFSET_DEG, pos);
            g_homing     = 1;
        } else {
            /* Энкодер восстановился после провала диагностики: привязываемся
             * на месте, движение — только по явной команде оператора. */
            g_target_deg = pos;
            g_homing     = 0;
        }
        return;
    }

    g_enc_counts  += enc_wrap_delta(rd->position, g_enc_raw_prev);
    g_enc_raw_prev = rd->position;
}

/* --- Фильтр выбросов показаний энкодера --- */

/* Пороги в отсчётах энкодера (позиция за 1 мс и потолок неоднозначности wrap) */
#define OUTLIER_DELTA_COUNTS ((int32_t)(ENCODER_OUTLIER_MAX_DELTA_DEG / 360.0f * \
                                        (float)ENCODER_COUNTS_REV))
#define OUTLIER_BUDGET_MAX_MS 20U   /* 20 мс × 3° = 60°, дальше wrap неоднозначен */
#define OUTLIER_MS_CYCLES     (SYSCLK_HZ / 1000U)

static uint32_t s_out_t0      = 0;  ///< Момент сэмпла последнего принятого чтения (DWT)
static uint32_t s_pend_raw    = 0;  ///< Кандидат новой позиции (raw)
static uint8_t  s_pend_streak = 0;  ///< Согласных чтений кандидата подряд
static uint32_t s_pend_t0     = 0;  ///< Момент сэмпла последнего чтения кандидата (DWT)

/* Бюджет сдвига по фактическому времени между сэмплами: elapsed_ms × MAX_DELTA.
 * Время (DWT), а не число исполненных тиков: пауза главного цикла (например,
 * UART-обмен с TMC2209) растягивает интервал между сэмплами, и валидное чтение
 * при быстром движении иначе выглядело бы выбросом. */
static int64_t outlier_budget(uint32_t since_cycles)
{
    uint32_t ms = since_cycles / OUTLIER_MS_CYCLES;
    if (ms < 1U) ms = 1U;
    if (ms > OUTLIER_BUDGET_MAX_MS) ms = OUTLIER_BUDGET_MAX_MS;
    return (int64_t)ms * OUTLIER_DELTA_COUNTS;
}

/**
 * @brief Фильтр выбросов: правдоподобно ли новое показание энкодера?
 * @param[in] rd Чтение со статусом BISS_OK / BISS_ERR_WARNING (сэмпл g_sample_t).
 * @return 1 — принять (передать в Encoder_Accumulate), 0 — отбросить.
 *
 * Показание отбрасывается, если сдвиг от последней принятой позиции превышает
 * физически возможный (ENCODER_OUTLIER_MAX_DELTA_DEG за 1 мс, бюджет
 * масштабируется на реальное время между сэмплами, но не более 60° — дальше
 * дельта неоднозначна из-за перехода через ноль). Единичные выбросы (CRC6
 * слабая — искажённый кадр проходит с вероятностью ~1/64) не дёргают контур.
 *
 * Реальный скачок позиции (проскальзывание муфты, восстановление энкодера
 * после долгой потери связи на ходу) отличается от выброса устойчивостью:
 * ENCODER_OUTLIER_STREAK согласных чтений подряд — и позиция перепривязывается
 * штатным путём (дельта через Encoder_Accumulate).
 */
static uint8_t Encoder_FilterOutlier(const BiSS_Reading *rd)
{
    /* Первое чтение — якорь, фильтровать не с чем */
    if (g_enc_raw_prev == 0xFFFFFFFF) {
        s_out_t0      = g_sample_t;
        s_pend_streak = 0;
        return 1;
    }

    int32_t d = enc_wrap_delta(rd->position, g_enc_raw_prev);
    if (d < 0) d = -d;
    if (d <= outlier_budget(g_sample_t - s_out_t0)) {
        s_out_t0      = g_sample_t;
        s_pend_streak = 0;
        return 1;
    }

    /* Вне бюджета: копим подтверждения новой позиции */
    if (s_pend_streak) {
        int32_t pd = enc_wrap_delta(rd->position, s_pend_raw);
        if (pd < 0) pd = -pd;
        s_pend_streak = (pd <= outlier_budget(g_sample_t - s_pend_t0))
                        ? (uint8_t)(s_pend_streak + 1U) : 1U;
    } else {
        s_pend_streak = 1;
    }
    s_pend_raw = rd->position;
    s_pend_t0  = g_sample_t;

    if (s_pend_streak >= ENCODER_OUTLIER_STREAK) {
        /* Новая позиция устойчива — это реальное движение, принимаем */
        s_out_t0      = g_sample_t;
        s_pend_streak = 0;
        return 1;
    }

    g_outlier_cnt++;
    return 0;
}

/* --- CL ↔ OL --- */

/**
 * @brief Управление переключением режимов CL/OL.
 * @param[in] enc_ok Флаг валидности данных энкодера в текущем тике.
 *
 * Если энкодер не отвечает более ENCODER_FAIL_MS, система переходит в Open-Loop.
 * При восстановлении связи возвращается в Closed-Loop со сбросом PID.
 */
static void Mode_Update(uint8_t enc_ok)
{
    if (enc_ok) {
        g_enc_fail_cnt = 0;
        if (g_mode == MODE_OL) {
            g_mode = MODE_CL;
            Control_Reset();
        }
    } else {
        g_enc_fail_cnt++;
        if (g_mode == MODE_CL && g_enc_fail_cnt >= (ENCODER_FAIL_MS / POLL_INTERVAL_MS)) {
            g_mode = MODE_OL;
            g_ol_pos = COUNTS_TO_DEG(g_enc_counts);
        }
    }
}

/* --- Управление мотором --- */
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

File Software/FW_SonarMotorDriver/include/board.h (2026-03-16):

/**
 * @file board.h
 * @brief Аппаратная конфигурация и параметры системы.
 *
 * Файл содержит определения выводов (GPIO), параметры тактирования, настройки периферии
 * (UART, SPI, TIM) и конфигурационные константы для алгоритмов управления (PID, TMC2209).
 * Является центральной точкой настройки аппаратной части проекта.
 */

#ifndef BOARD_H
#define BOARD_H

#include "stm32f1xx_hal.h"

/* -------- RCC — тактирование (HSI/2 × PLL12 = 48 МГц) -------- */
#define SYSCLK_HZ               48000000U
#define APB1_CLK_HZ             (SYSCLK_HZ / 2U)   /* 24 МГц (макс. 36 МГц) */
#define APB2_CLK_HZ             SYSCLK_HZ           /* 48 МГц */
#define TIM2_CLK_HZ             (APB1_CLK_HZ * 2U)  /* 48 МГц (APB1 prescaler > 1 → ×2) */
#define TIM4_CLK_HZ             TIM2_CLK_HZ         /* TIM4 для STEP импульсов */

/* -------- TIM2 — периодический опрос энкодера -------- */
#define POLL_INTERVAL_MS        1U                            /* Период опроса: 1 мс (1 кГц) */
#define POLL_FREQ_HZ            (1000U / POLL_INTERVAL_MS)    /* 1 кГц */

/* -------- GPIO — светодиод (Blue Pill: PC13, active LOW) -------- */
#define LED_PORT                GPIOC
#define LED_PIN                 GPIO_PIN_13
#define LED_TOGGLE_INTERVAL     (POLL_FREQ_HZ / 2U)  /* Индикатор активности ~1 Гц */

/* -------- SYNC — SYNC_OUT / SYNC_IN -------- */
#define SYNC_OUT_PORT           GPIOB
#define SYNC_OUT_PIN            GPIO_PIN_9   /* PB9 — SYNC_OUT (HIGH=позиция достигнута) */
#define SYNC_IN_PORT            GPIOB
#define SYNC_IN_PIN             GPIO_PIN_12  /* PB12 — SYNC_IN (внешний триггер) */
/* Обратная совместимость */
#define SYNC_PORT               SYNC_OUT_PORT
#define SYNC_PIN                SYNC_OUT_PIN

/* -------- SPI1 + THVD1452 — энкодер LENZ IRS (BiSS C) -------- */
#define ENCODER_RESOLUTION_BITS 17U     /* 17 для IRS-I34/I50/I60; 18 для I70/I80/I90 */
#define ENCODER_ACCURACY_DEG    0.05f   /* Погрешность, град (IRS-I50: 0.05, I60: 0.042, I34: 0.15) */
#define ENCODER_STARTUP_MS      50U     /* Время готовности после подачи питания */
#define ENCODER_COUNTS_REV      131072U /* 2^17 для 17-бит энкодера */
#define ENCODER_FAIL_MS         500U    /* Мс без ответа → переход в open-loop */
#define XCVR_DE_PORT            GPIOB
#define XCVR_DE_PIN             GPIO_PIN_0  /* Driver Enable  (active HIGH → TX MA) */
#define XCVR_RE_PORT            GPIOB
#define XCVR_RE_PIN             GPIO_PIN_1  /* Receiver Enable (active LOW → RX SLO) */

/* -------- Режим управления двигателем (compile-time) -------- */
#define MOTOR_DRIVER_MODE_STEP_DIR_VAL  0   /* STEP/DIR импульсы от MCU (TIM4) */
#define MOTOR_DRIVER_MODE_UART_VAL      1   /* VACTUAL / internal pulse generator TMC2209 */
#define MOTOR_DRIVER_MODE               MOTOR_DRIVER_MODE_STEP_DIR_VAL

/* -------- TIM4 + TMC2209 — шаговый двигатель -------- */
/* Внимание: VS питание драйвера ОБЯЗАТЕЛЬНО подключать с электролитическим конденсатором! */
#define MOTOR_FULL_STEPS_REV    200U    /* Полных шагов на оборот (200 = 1.8°, 400 = 0.9°) */
#define TMC2209_MICROSTEPS      256U    /* Микрошаг: 1, 2, 4, 8, 16, 32, 64, 128, 256 */
#define MOTOR_STEPS_PER_REV     (MOTOR_FULL_STEPS_REV * TMC2209_MICROSTEPS)
#define MOTOR_DIR_INVERT        1       /* 1 = инвертировать направление */
#define MAX_SPEED_DEG_S         1200U   /* Максимальная скорость, град/с */
#define MAX_STEPS_PER_POLL      ((MAX_SPEED_DEG_S * MOTOR_STEPS_PER_REV + 360U * POLL_FREQ_HZ - 1U) / (360U * POLL_FREQ_HZ))
#define STEP_PORT               GPIOB
#define STEP_PIN                GPIO_PIN_8
#define STEP_PULSE_US           2U      /* Длительность импульса STEP (TMC2209: мин. 1–2 мкс) */
#define DIR_PORT                GPIOB
#define DIR_PIN                 GPIO_PIN_7
#define ENABLE_PORT             GPIOB
#define ENABLE_PIN              GPIO_PIN_6  /* ENN: LOW = включён, HIGH = выключен */
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

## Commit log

2026-02-27 Initial commit: firmware (BiSS C, USB CDC) and PCB design
    Made-with: Cursor
    [PCB_SonarMotorDriver.PcbDoc, PCB_SonarMotorDriver.PrjPcb, Sheet_SonarMotorDriver.SchDoc]
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2026-02-28 refactor: transition to non-blocking architecture with USB ring buffer
    - Implement non-blocking polling timer architecture in main loop
    - Add ring buffer (FIFO) to USB CDC TX to ensure reliable data transmission at 500Hz
    - Centralize board configuration and macros into include/board.h
    - Refactor hardware initialization to use proper HAL MSP functions for SPI and TIM
    - Restructure and simplify code comments
    - Update README.md to reflect new architecture and configuration options
    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
2026-02-28 refactor: stabilize control loop and migrate BiSS to DMA
    Move core firmware modules to include/src structure, switch BiSS-C reads to asynchronous SPI DMA, and update stepper/PID control defaults for smoother and more deterministic closed-loop behavior.
    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
    [biss_c.c, board.h, main.c]
2026-03-01 Рефакторинг: удаление неиспользуемых функций, упрощение комментариев, обновление README
    - Удалены: PID_SetLimits, Stepper_Step, BiSS_StatusStr, g_stats, g_tx_busy
    - Stepper_SetDir сделан static (используется только внутри stepper.c)
    - Упрощено форматирование комментариев: однострочные заголовки, лёгкие разделители
    - README: схема PID-регулятора в классическом виде (замкнутый контур), обновлён API
    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
2026-03-01 UART DMA: дублирование команд и телеметрии, группировка board.h
    - Добавлен модуль UART (USART1, PA9/PA10) с DMA: RX circular, TX normal
    - Команды и телеметрия дублируются на USB CDC и UART
    - Константы в board.h сгруппированы по периферии
    - Обновлены README
    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
2026-03-02 feat: scan sector command, sync pin, stop any movement (не протестировано)
    - Add scan=start,end,step,delay command (zigzag until stop)
    - Add stop command (stops any motor movement)
    - Add sync pin (PA1): HIGH=position reached, LOW=moving
    - Motor enabled by default at startup
    - Update README with scan docs and startup behavior
    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
2026-03-03 feat: continuous rotation (t=+/t=-) and infinite scan (scan=s,+/-)
    Added two new motor operating modes:
    - t=+/t=-: continuous rotation at max speed without PID
    - scan=s,+,st,d / scan=s,-,st,d: step-by-step scanning in one direction
    Float position counter overflow protection for long-running operation.
    README updated: command summary table, new mode descriptions.
    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
2026-03-05 TMC2209: UART (PA2/PA3), DIAG (PA7). Обновлён README. Не протестировано.
    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
    [Sheet_SonarMotorDriver.SchDoc]
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2026-03-14 Add TMC2209 stepper motor control with USB CDC interface
    - Created platformio.ini for STM32F446RE configuration.
    - Implemented main.c for USB CDC communication and TMC2209 command processing.
    - Developed tmc2209.c for TMC2209 driver functionalities including UART and STEP/DIR modes.
    - Added usb_cdc.c for USB CDC initialization, transmission, and reception handling.
    - Configured usbd_conf.c for USB OTG FS integration and low-level USB handling.
    - Defined USB descriptors in usbd_desc.c for device identification and configuration.
    [Board_40mm_30mm.DXF, Board_40mm_30mm.SLDPRT]
2026-03-14 Test_TMC2209: UART half-duplex, SLAVECONF, validation for TMC2209 single-wire
    - HAL_HalfDuplex_Init, EnableTransmitter/EnableReceiver for single-wire PDN_UART
    - TX pin: open-drain, RX validation (rsp[1]==0xFF)
    - SLAVECONF SENDDELAY=4 before first read
    - test_commands.py for automated tests
    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
2026-03-14 Refactor: extract TMC2209 reusable library
    - New lib/tmc2209: platform-agnostic driver (tmc2209.c, tmc2209.h, types, regs, port)
    - Port layer: tmc2209_port_stm32_hal.c for STM32 HAL (full-duplex UART)
    - API: tmc2209_init, read/write regs, set_current, set_vactual, enable/disable, diagnostics
    - Config via tmc2209_config_t, I/O via tmc2209_io_t callbacks
    - docs/TMC2209_API.md: full API documentation
    - main.c: CLI example using library, STEP/DIR PWM remains in app layer
    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
2026-03-14 feat(TMC2209): expand library API, docs and examples
    - Add OTP, CoolStep, StallGuard, ChopConf/PwmConf support
    - Add current/power, standby, internal Rsense, diagnostics
    - Add multi-device scan, presets, shadow registers
    - Add docs/TMC2209_API.md and examples in docs/examples/
    [01_basic_init.c, 03_diagnostics.c, 05_multi_device.c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]
2026-03-14 WIP: integrate TMC2209 library into FW_SonarMotorDriver (intermediate)
    - Add lib/tmc2209 from Test_TMC2209
    - Add STM32F1 HAL port adapter (tmc2209_port_stm32_hal)
    - Replace old IRQ-based tmc2209.c with library wrapper
    - Extend board.h TMC config; remove TMC IRQ from uart.c
    - STEP/DIR motion unchanged; blocking init via InitStart/Poll
    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
    [board.h, uart.c]
2026-03-14 FW: motor-driver layer, UART на PA9/PA10
    - Единый motor_driver слой: TMC2209 + STEP/DIR + UART motion
    - Удалены stepper.c/h и tmc2209.c/h (app wrapper)
    - main.c использует только MotorDriver_* API
    - Режимы STEP_DIR и UART (board.h: MOTOR_DRIVER_MODE)
    - UART команд/телеметрии переведён на USART1 (PA9/PA10)
    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
2026-03-14 FW: DMA UART, continuous STEP/DIR timer, async TMC diag. Ne protestirovano.
    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
    [wch-link.cfg]
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2026-03-15 feat: Implement TMC2209 motor driver, PID control, UART communication, and command parsing, along with a new dedicated TMC2209 test project.
    [wch-link.cfg]
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2026-04-11 Remove obsolete PCB and schematic files for SonarMotorDriver from the repository.
    [PCB_SonarMotorDriver.PcbDoc, Sheet_SonarMotorDriver.SchDoc]
2026-04-11 Update .gitignore and README.md for improved structure and clarity; remove outdated CAD and datasheet files.
    [1.STEP, 1812B226K250NT.SLDPRT, 1812B226K250NT.stp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]
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2026-07-10 Update README.md to clarify TMC2209 functionality and add new simulation firmware directory; remove outdated PCB and BOM files from the repository.
    [Board_40mm_30mm.SLDPRT, PCB_SonarMotorDriver.PrjPcb, wch-link.cfg]
